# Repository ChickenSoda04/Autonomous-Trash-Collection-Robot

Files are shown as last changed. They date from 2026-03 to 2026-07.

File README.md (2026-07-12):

<div align="center" markdown="1">

# Autonomous Trash Collection

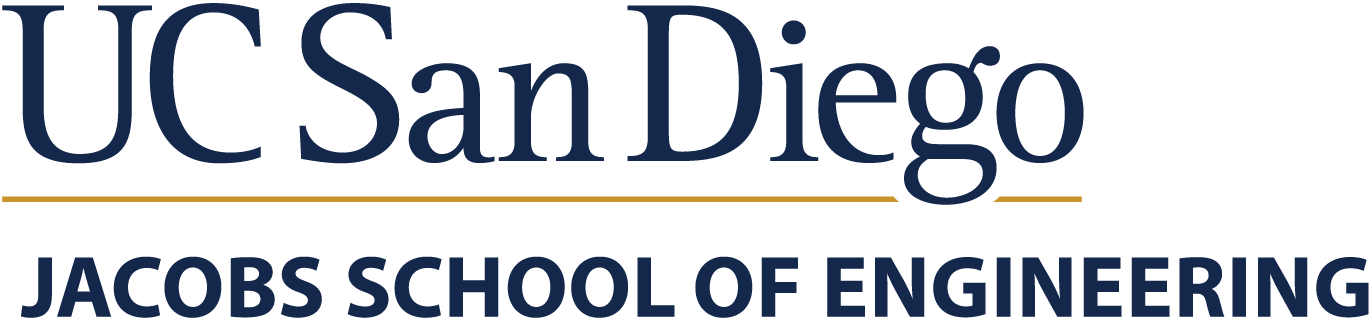
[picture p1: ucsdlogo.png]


### Team 10 & 15
### ECE/MAE 148 Final Project Winter 2026

</div>

---

## Table of Contents
1. [Team Members](#team-members)
2. [Overview](#overview)
3. [What We Promised](#what-we-promised)
4. [Accomplishments](#accomplishments)
5. [Demonstration](#demonstration)
6. [Challenges](#challenges)
7. [Project Design](#robot-arm-design)
8. [References](#references)
9. [Acknowledgments](#acknowledgments)

---

## Team Members
Team 15
- David Carrillo - MAE
- Darin Djapri 
- Lek Man- MAE
- Ryan Chen- ECE

Team 10
- Marcus Greenan - MAE
- Giovanni Clark - ECE
- Harihar Kaushik - ECE
- Lucas Johnson - ECE

---

## Overview
The **Autonomous Trash Collection** robot is a self-driving car equipped with a robotic arm that searches for and picks up litter. Using computer vision, the robot identifies trash on the ground, navigates toward it autonomously, and uses the robotic arm to collect and place it in the bin. The robot can then deliver the trash to a designated dropoff location.

---

## What We Promised

### Must Have:
- Autonomous driving and navigation
- Computer vision-based trash detection using OAK-D camera
- Robotic arm that picks up detected trash
- Deposits collected trash into an onboard bin
- Stop and approach detected trash accurately

### Nice to Have:
- Multiple trash detection and collection in a single run
- Sorting trash by type (recyclable vs. non-recyclable)
- Return to base behavior after bin is full

---

## Accomplishments
- Successfully integrated OAK-D camera with YOLOv8 model for real-time trash detection (~85% accuracy)
- Developed a ROS2 package to calculate the angle and distance from the camera to detected trash
- 3D printed a robotic arm mount for the car chassis
- Programmed the robotic arm to execute pick and place sequences upon trash detection, and integrated this functionality into a ROS2 node
- Developed a ROS2 package to facilitate centroid tracking with PID control to navigate to object
- Put together a ROS2 node based on the existing UCSD node package to identify an object, drive to it, and stop a certain distance away before triggering the arm pick-up package.
- Created a modified version of the UCSD Robocar Docker container incorporating all the aforementioned packages.

---

## Demonstration

[Full Demo Video](https://youtu.be/k4CTWPhfO1g) [Alternate Angle](https://youtu.be/v82C47zf4og)  
[Arm Demo](https://drive.google.com/file/d/1cBP66cU5hcg2m4QuWV22k2muI_fQQhjR/view)  
[Object Detection and Following Demo](https://youtu.be/KGpaVR8SIbE)  
[LiDAR Testing](https://drive.google.com/file/d/15g1UKWkqdbuN8HR0NhmWQhi5QHV1ik_H/view?usp=drivesdk)  

---

## Challenges
- **Arm calibration:** Getting the robotic arm to reliably pick up small/irregular objects required extensive tuning of servo positions and approach angles.
  - Solved by creating a multi-step approach sequence and adding a gripper feedback check.
- **Trash detection accuracy:** The model initially struggled with varying lighting conditions outdoors.
  - Improved the training dataset with augmented images under different lighting conditions, boosting accuracy.
- **Navigation precision:** Stopping at the exact distance needed for the arm to reach the trash was difficult.
  - Used LiDAR distance feedback in combination with camera angle data to fine-tune the stopping position.
- **ROS2 node conflicts:** Running the detection pipeline and arm control simultaneously caused timing conflicts.
  - Resolved by restructuring the node communication pipeline with proper topic queuing.
- **USB Bandwidth Challenges:** USB bandwidth issues stem from the fact that each group of USB 2.0 and USB 3.0 ports on the Raspberry Pi share a bus, and the high refresh rate required for each device in this application. The OAK-D initialization pipeline also switches between USB 2.0 and 3.0 pipelines, adding to port assignment confusion and bandwidth problems.
  -  These issues were partially solved using permanent device ID based assignments to ensure consistency between launches, although these were challenging to make consistent owing to permissions issues between the Docker Container and the host machine. If the permissions are made consistent, device ID based port assignments would be a good solution.
  -  Running inference on the OAK-D Lite camera saves significant bandwidth, since the device only needs to pass results over USB rather than images. Even so, the framerate had to be reduced from the standard 30 FPS to 10 FPS. The same refresh rate modification was applied to the LIDAR.
- **Power Challenges:** Power issues plagued this project. These issues were only partially solved in the interest of longevity, but safe permanent solutions are feasible. Current limiting was a recurring problem with this project, with certain actuator activations triggering brownouts.
  - Partially addressed the problem by simply using mains power to power the arm. However, this could be safely addressed by using a higher rated DC/DC converter. We were unable to source the parts needed in time, and thought it unsafe to splice more wiring to add another DC/DC converter.

---

## Robot Arm Design
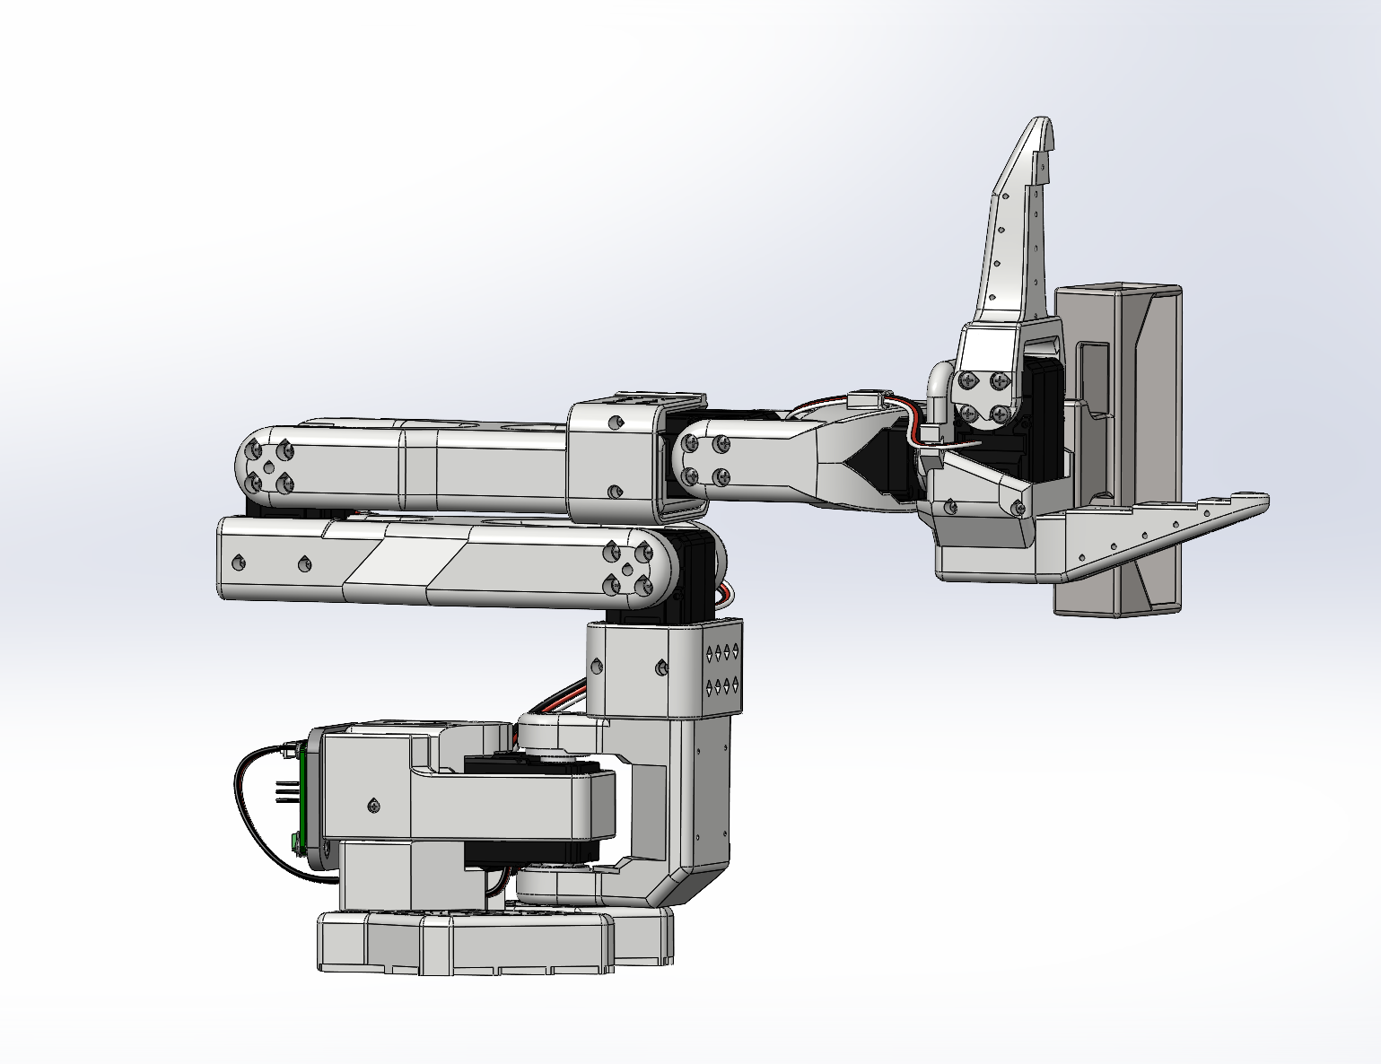
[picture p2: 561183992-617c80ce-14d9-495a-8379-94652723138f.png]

Arm Calibration Testing

## Object Navigation and Tracking

Watch the video (https://youtu.be/KGpaVR8SIbE?si=vM9rUNm2YVQ-w0Mx)

### Hardware Components List
- SO101 Arm by The Robot Studio 
- OAK-D Camera
- STS3215 Servos
- Motor Control Board
- USB-C Cable

## Car Platform

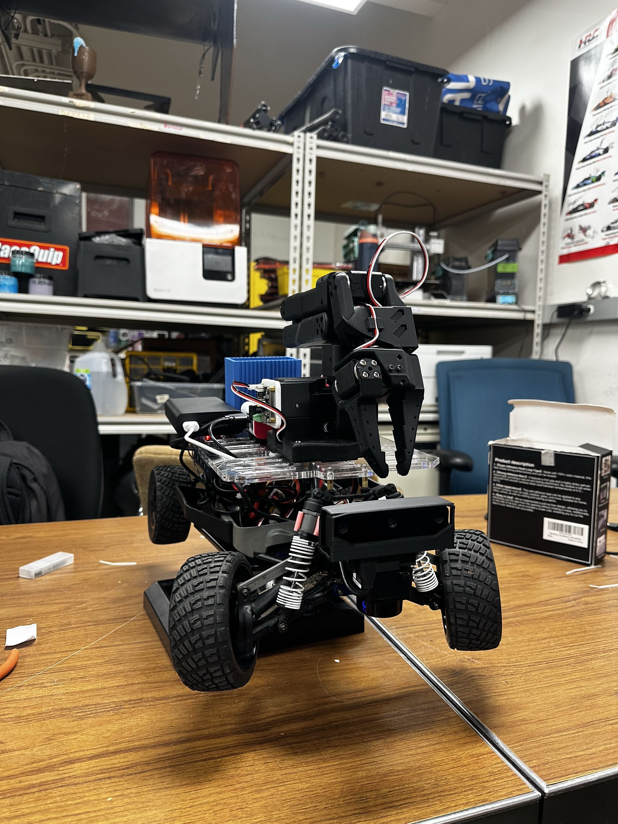
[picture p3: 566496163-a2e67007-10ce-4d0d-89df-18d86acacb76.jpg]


### Hardware Components List
- Base Driving Platform (Traxxas Chassis with Motor and Steering Servo)
- Flipsky FSESC 6.7 Pro and Antispark Switch Pro with Trampa Servo PDB
- 12V to 12V + 5V DC/DC converter (16A)
- LiPo 4S Battery
- OAK-D Lite Camera 
- LDRobot LDS19 LIDAR
- Raspberry Pi 5 8GB
- Powered USB A 3.0 Hub
- Required Cables

---

## Project Demo
Watch the video (https://youtu.be/5j4aBRYknjA)

## References
- [TheRobotStudio](https://github.com/TheRobotStudio/SO-ARM100)
- [ECE/MAE148 Documentation](https://docs.google.com/document/d/1VeWe5lWh3oB3GlEVowoPrXruzKi2Am8tP-r6KEEmcX8/edit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)
- [UCSD Robocar Framework](https://gitlab.com/ucsd_robocar2)
- [Luxonis Documentation](https://docs.luxonis.com/hardware/products/OAK-D%20Lite)
- [Trash Detection Dataset - Roboflow](https://universe.roboflow.com)
- [LDRobot LIDAR GitHub](https://github.com/ldrobotSensorTeam)
- [Luxonis Blob Converter](https://blobconverter.luxonis.com/)
- [Label Studio](https://labelstud.io/)

---

## Acknowledgments
Thank you to Professor Jack Silberman and our TAs!

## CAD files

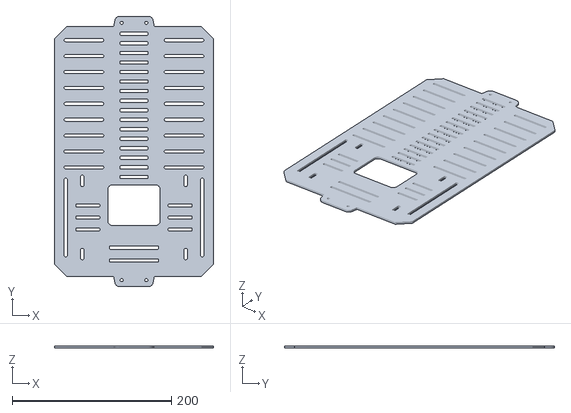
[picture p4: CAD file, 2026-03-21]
Misc_STL/DeckPlateAcl (1).stl
200.0 x 340.0 x 3.00

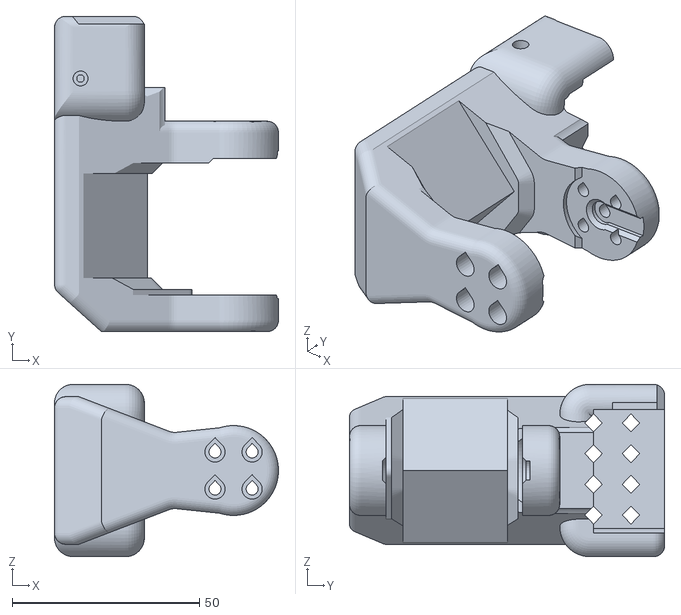
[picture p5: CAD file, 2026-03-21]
SO101_STL_Files/Rotation_Pitch_SO101.stl
59.8 x 84.2 x 46.0

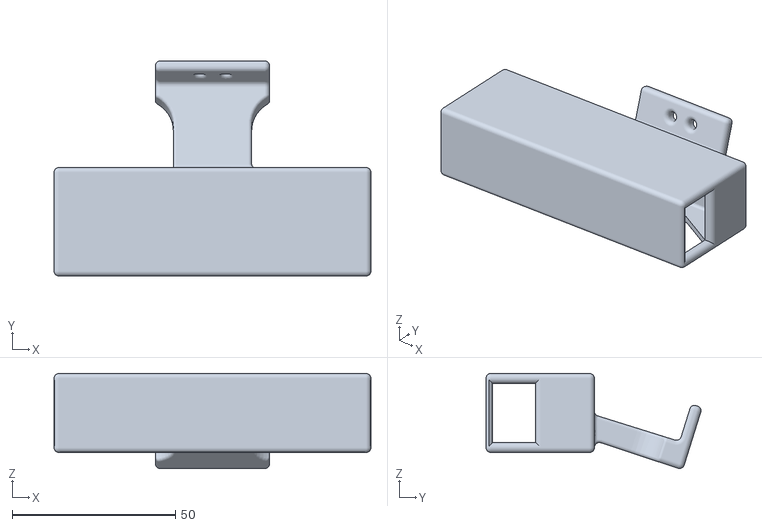
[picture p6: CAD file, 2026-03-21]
Misc_STL/RobotArmCAM (1).STL
97.0 x 65.8 x 29.1

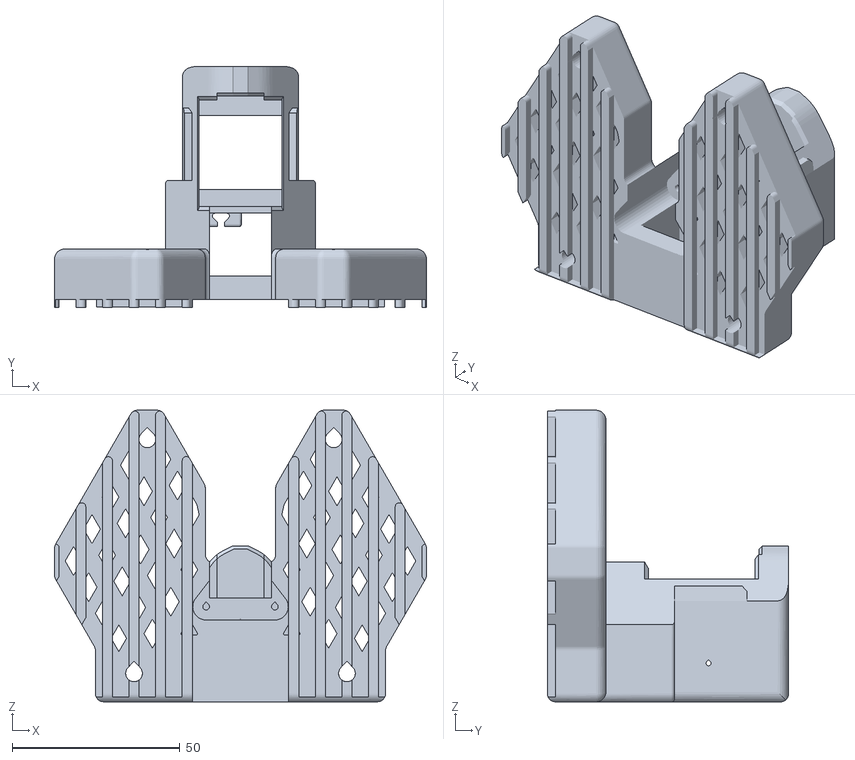
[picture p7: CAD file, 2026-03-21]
SO101_STL_Files/Base_SO101.stl
110.9 x 72.0 x 87.0

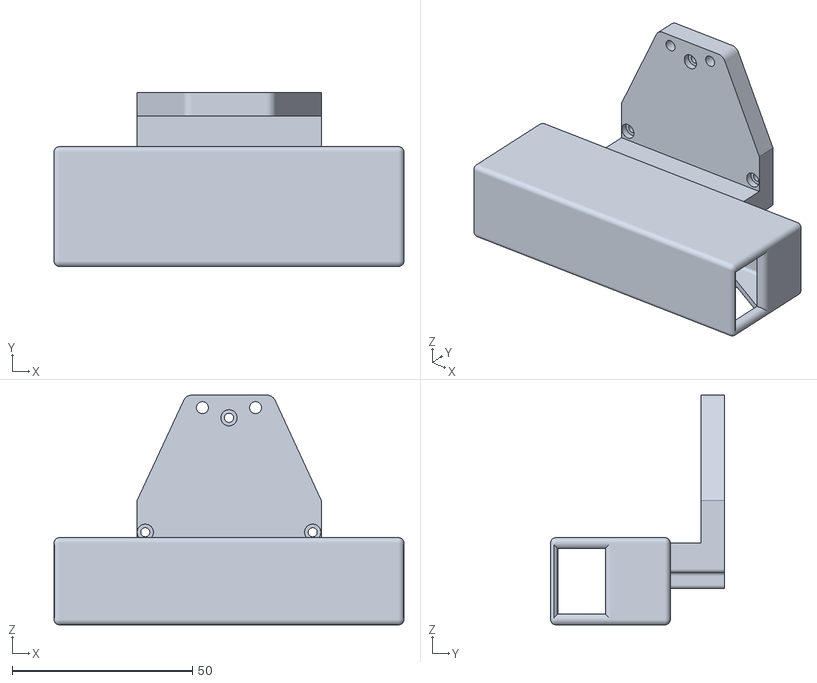
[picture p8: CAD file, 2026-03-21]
Misc_STL/Lidar+Cam (1).STL
97.0 x 48.2 x 63.7

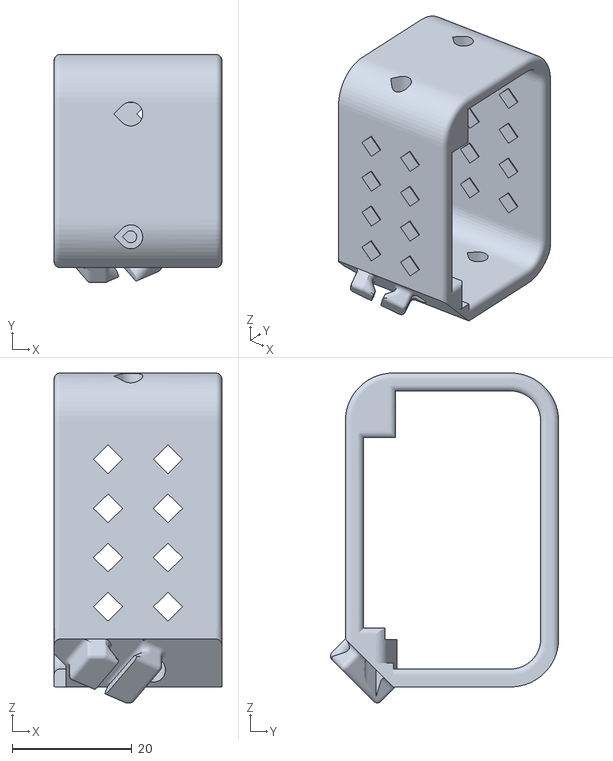
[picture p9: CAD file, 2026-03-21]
SO101_STL_Files/Motor_holder_SO101_Base.stl
28.0 x 38.1 x 55.1

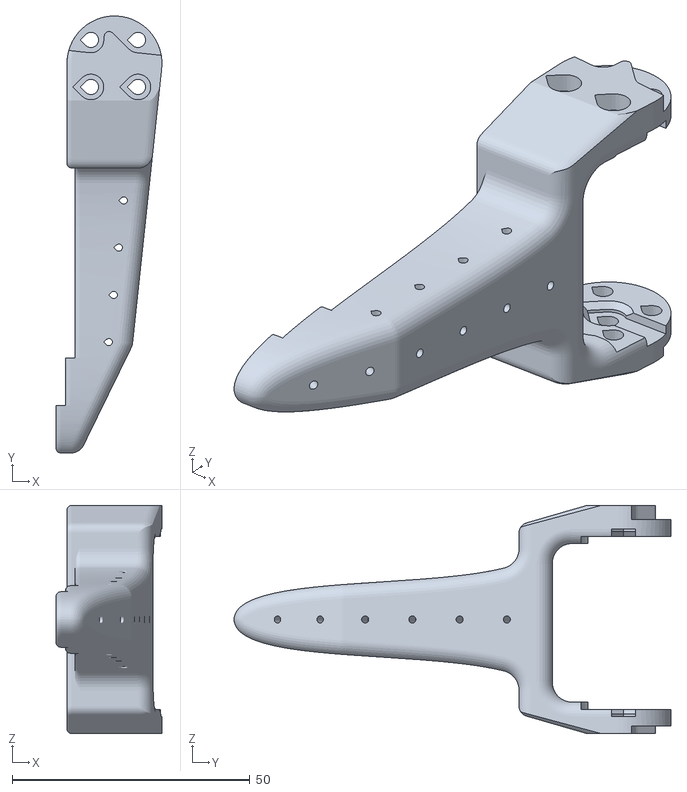
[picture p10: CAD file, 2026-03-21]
SO101_STL_Files/Moving_Jaw_SO101.stl
22.3 x 92.0 x 48.0

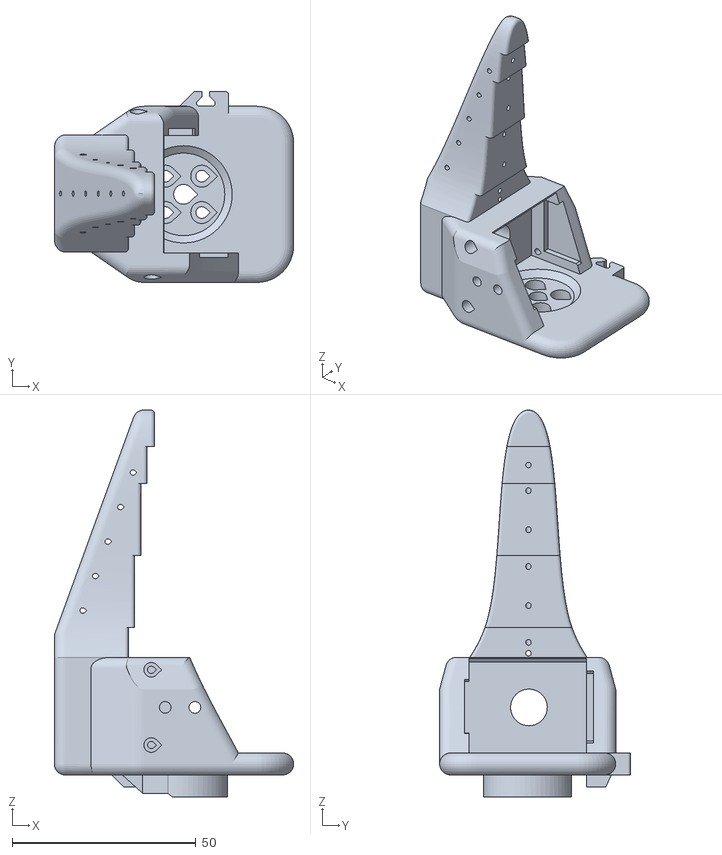
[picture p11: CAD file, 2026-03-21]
SO101_STL_Files/Wrist_Roll_Follower_SO101.stl
65.2 x 52.0 x 105.4

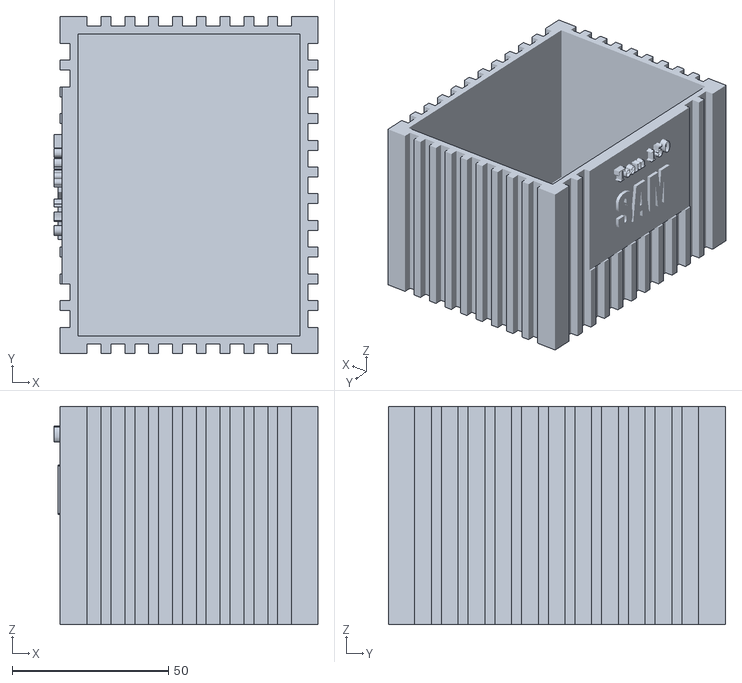
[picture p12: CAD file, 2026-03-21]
SO101_STL_Files/Trash can new 2 Mae 148 Final.stl
84.5 x 108.0 x 69.8

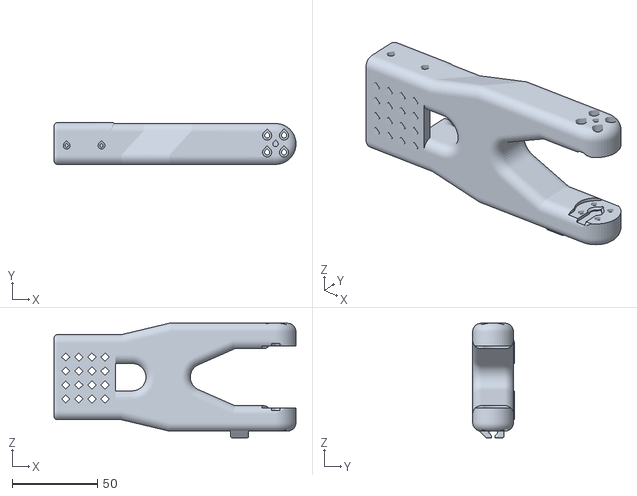
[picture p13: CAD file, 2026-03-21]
SO101_STL_Files/Upper_arm_SO101.stl
142.1 x 24.5 x 67.3

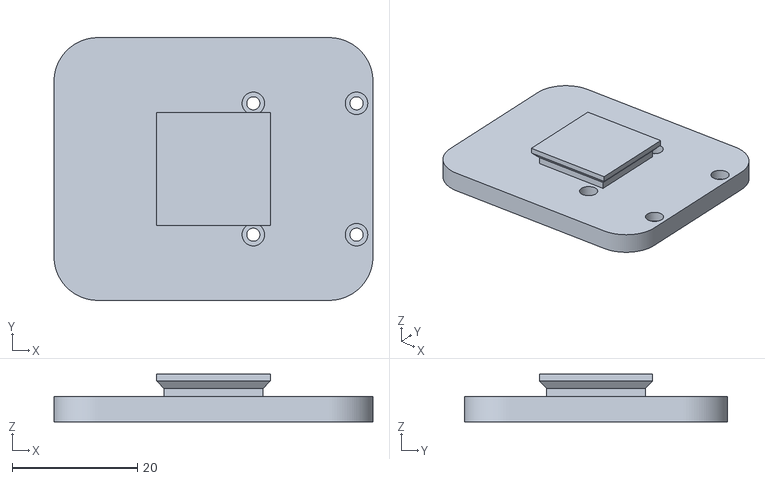
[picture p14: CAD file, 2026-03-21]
SO101_STL_Files/Seeedstudio_Mounting_Plate_SO101.stl
51.0 x 42.0 x 7.60

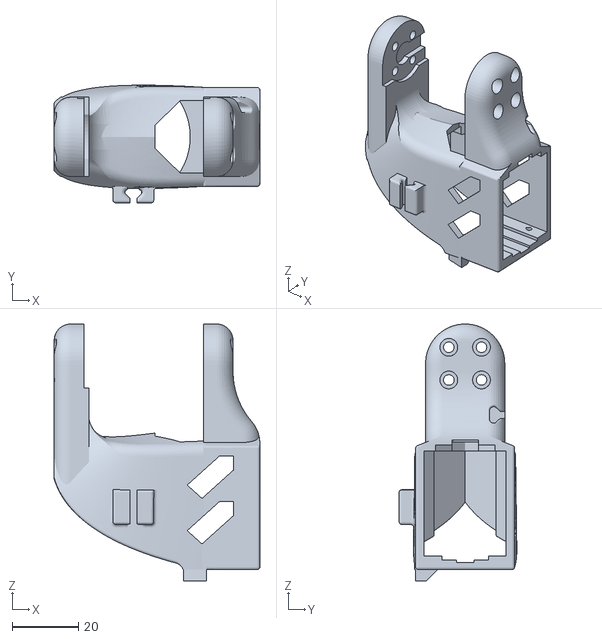
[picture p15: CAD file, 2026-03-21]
SO101_STL_Files/Wrist_Roll_Pitch_SO101.stl
62.3 x 35.7 x 77.8

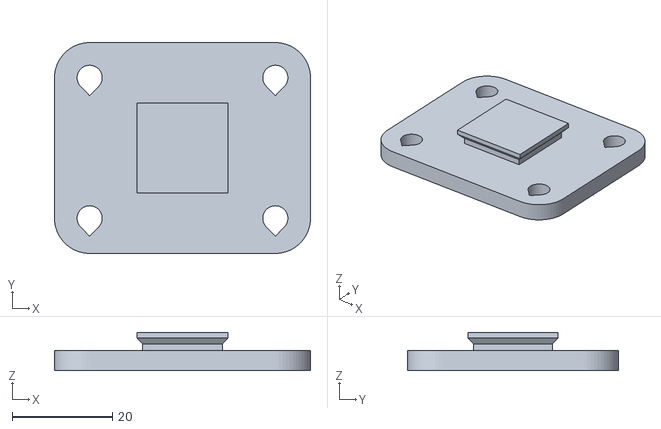
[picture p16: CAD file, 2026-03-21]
SO101_STL_Files/WaveShare_Mounting_Plate_SO101.stl
51.0 x 42.0 x 7.60

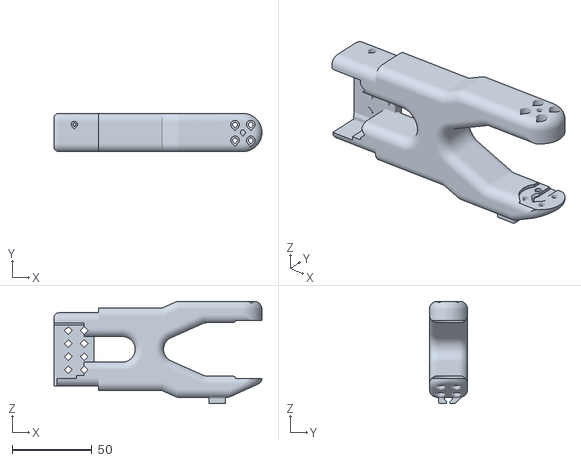
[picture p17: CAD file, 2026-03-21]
SO101_STL_Files/Under_arm_SO101.stl
130.7 x 24.0 x 64.4

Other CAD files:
SO101_STL_Files/Motor_holder_SO101_Wrist.stl
SO101_STL_Files/Base_motor_holder_SO101.stl

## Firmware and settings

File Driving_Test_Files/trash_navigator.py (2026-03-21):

#!/usr/bin/env python3
"""
trash_navigator.py
ROS2 node — OAK-D Myriad X inference + LD19 LiDAR stop.

Bandwidth optimisations:
  - Inference runs on Myriad X — only NN results cross USB, not full frames
  - No onnxruntime, no Pi CPU inference load
  - ImageManip converts video to BGR888p on-device before NN
  - maxSize=1 on all queues
  - USB2 mode — stable connection
  - Timer at 10Hz matches camera FPS
  - LiDAR reads 1 packet per loop
  - Single-threaded ROS executor
  - Preallocated numpy arrays
"""

import math
import time
import depthai
import numpy as np
import cv2
import serial
import rclpy
from rclpy.node import Node
from geometry_msgs.msg import Twist

# ── CONFIGURATION ─────────────────────────────────────────────────────────────
BLOB_PATH        = "/home/projects/best_simplified_openvino_2021.4_6shave.blob"  # Or the path to your blob
CLASSES          = ["Raisin Box"] #Make sure all these params match your model, check your data.yaml for this info
NUM_CLASSES      = len(CLASSES)
IMG_SIZE         = 416
CONF_THRES       = 0.5
IOU_THRES        = 0.4
NORM_FACTOR      = IMG_SIZE / 2.0

STOP_DISTANCE_M  = 0.16
LIDAR_PORT       = "/dev/ttyUSB0"
LIDAR_BAUD       = 230400
FORWARD_CONE     = 20.0
MIN_RANGE        = 0.15
MAX_RANGE        = 1.50
CLUSTER_DIST     = 0.08
MIN_CLUSTER_SIZE = 2
PACKETS_PER_LOOP = 1             # One LiDAR packet per loop — minimal USB traffic

KP            = 1.0
MAX_THROTTLE  = 0.2

HEADER      = 0x54
VER_LEN     = 0x2C
PACKET_SIZE = 47


# ── YOLOV8 PARSER ─────────────────────────────────────────────────────────────
def parse_yolov8(raw, conf_thres, iou_thres, img_size, nc):
    data        = np.asarray(raw, dtype=np.float32)
    total       = 4 + nc
    num_anchors = data.size // total
    data        = data.reshape(total, num_anchors).T
    normalised  = data[:, :4].max() <= 1.0

    boxes, scores, class_ids = [], [], []
    for row in data:
        cls_scores = row[4:]
        cls_id     = int(cls_scores.argmax())
        conf       = float(cls_scores[cls_id])
        if conf < conf_thres:
            continue
        cx, cy, w, h = row[:4]
        if normalised:
            cx, cy, w, h = (cx * img_size, cy * img_size,
                            w  * img_size, h  * img_size)
        x1 = max(0, int(cx - w / 2))
        y1 = max(0, int(cy - h / 2))
        x2 = min(img_size - 1, int(cx + w / 2))
        y2 = min(img_size - 1, int(cy + h / 2))
        if x2 - x1 < 2 or y2 - y1 < 2:
            continue
        boxes.append([x1, y1, x2 - x1, y2 - y1])
        scores.append(conf)
        class_ids.append(cls_id)

    if not boxes:
        return []
    idxs = cv2.dnn.NMSBoxes(boxes, scores, conf_thres, iou_thres)
    if len(idxs) == 0:
        return []
    idxs = idxs.flatten() if hasattr(idxs, 'flatten') else idxs
    return [(boxes[i], scores[i], class_ids[i]) for i in idxs]


# ── LIDAR HELPERS ─────────────────────────────────────────────────────────────
def lidar_read_packet(ser):
    try:
        b1 = ser.read(1)
        if not b1 or b1[0] != HEADER:
            return None
        b2 = ser.read(1)
        if not b2 or b2[0] != VER_LEN:
            return None
        rest = ser.read(PACKET_SIZE - 2)
        if len(rest) != PACKET_SIZE - 2:
            return None
        return b1 + b2 + rest
    except Exception:
        return None


def lidar_parse_packet(packet):
    start_angle = ((packet[5] << 8) | packet[4]) / 100.0
    end_angle   = ((packet[43] << 8) | packet[42]) / 100.0
    if end_angle < start_angle:
        end_angle += 360.0
    pts = []
    for i in range(12):
        off     = 6 + 3 * i
        dist_mm = (packet[off + 1] << 8) | packet[off]
        if dist_mm == 0:
            continue
        dist_m = dist_mm / 1000.0
        if dist_m < MIN_RANGE or dist_m > MAX_RANGE:
            continue
        angle_deg = start_angle + (end_angle - start_angle) * i / 11.0
        angle_deg = angle_deg % 360.0
        if not (angle_deg <= FORWARD_CONE or angle_deg >= (360.0 - FORWARD_CONE)):
            continue
        angle_rad = math.radians(angle_deg)
        x = dist_m * math.cos(angle_rad)
        y = dist_m * math.sin(angle_rad)
        pts.append((x, y, dist_m))
    return pts


def lidar_cluster(points):
    if not points:
        return []
    clusters = []
    current  = [points[0]]
    for i in range(1, len(points)):
        if math.hypot(points[i][0] - points[i-1][0],
                      points[i][1] - points[i-1][1]) <= CLUSTER_DIST:
            current.append(points[i])
        else:
            clusters.append(current)
            current = [points[i]]
    clusters.append(current)
    return [c for c in clusters if len(c) >= MIN_CLUSTER_SIZE]


def lidar_centroid_distance(clusters):
    best = MAX_RANGE
    for c in clusters:
        x = sum(p[0] for p in c) / len(c)
        y = sum(p[1] for p in c) / len(c)
        best = min(best, math.hypot(x, y))
    return best


# ── ROS2 NODE ─────────────────────────────────────────────────────────────────
class TrashNavigator(Node):

    def __init__(self):
        super().__init__('trash_navigator_node')
        self.publisher    = self.create_publisher(Twist, '/cmd_vel', 10)
        self.stopped      = False
        self.current_dist = MAX_RANGE

        self._init_oakd()
        self._init_lidar()

        # 10Hz matches camera FPS — no wasted loop iterations
        self.create_timer(0.1, self.navigation_loop)
        self.get_logger().info('TrashNavigator ready.')

    # ── OAK-D + Myriad X inference ────────────────────────────────────────────
    def _init_oakd(self):
        self._device = None
        self._q_nn   = None

        devices = depthai.Device.getAllAvailableDevices()
        if not devices:
            self.get_logger().error('No OAK-D device found.')
            return

        device = devices[0]
        if str(device.state) != 'XLinkDeviceState.X_LINK_UNBOOTED':
            self.get_logger().warn(
                'OAK-D not UNBOOTED: {}'.format(device.state))
            return

        pipeline = depthai.Pipeline()

        cam_rgb = pipeline.create(depthai.node.ColorCamera)
        cam_rgb.setResolution(
            depthai.ColorCameraProperties.SensorResolution.THE_1080_P)
        cam_rgb.setVideoSize(IMG_SIZE, IMG_SIZE)
        cam_rgb.setColorOrder(depthai.ColorCameraProperties.ColorOrder.BGR)
        cam_rgb.setInterleaved(False)
        cam_rgb.setFps(10)

        # Convert to BGR888p on-device before NN — no frame data crosses USB
        manip = pipeline.create(depthai.node.ImageManip)
        manip.initialConfig.setFrameType(depthai.RawImgFrame.Type.BGR888p)
        manip.setMaxOutputFrameSize(IMG_SIZE * IMG_SIZE * 3)
        cam_rgb.video.link(manip.inputImage)

        # Inference runs entirely on Myriad X
        nn = pipeline.create(depthai.node.NeuralNetwork)
        nn.setBlobPath(BLOB_PATH)
        nn.setNumInferenceThreads(2)
        nn.setNumNCEPerInferenceThread(1)
        nn.input.setBlocking(False)
        manip.out.link(nn.input)

        # Only NN results cross USB — tiny compared to full frames
        xout_nn = pipeline.create(depthai.node.XLinkOut)
        xout_nn.setStreamName("nn")
        nn.out.link(xout_nn.input)

        self._device = depthai.Device(pipeline, device, True)
        self._q_nn   = self._device.getOutputQueue(
            "nn", maxSize=1, blocking=False)
        self.get_logger().info('OAK-D Myriad X inference started.')

    # ── LiDAR init ────────────────────────────────────────────────────────────
    def _init_lidar(self):
        try:
            self._ser = serial.Serial(LIDAR_PORT, LIDAR_BAUD, timeout=0.005)
            self.get_logger().info('LiDAR opened on {}'.format(LIDAR_PORT))
        except serial.SerialException as e:
            self.get_logger().error('LiDAR error: {}'.format(e))
            self._ser = None

    # ── LiDAR distance ────────────────────────────────────────────────────────
    def _get_lidar_distance(self):
        if self._ser is None:
            return self.current_dist
        pts = []
        for _ in range(PACKETS_PER_LOOP):
            packet = lidar_read_packet(self._ser)
            if packet:
                pts.extend(lidar_parse_packet(packet))
        if not pts:
            return self.current_dist
        pts_sorted = sorted(pts, key=lambda p: math.atan2(p[1], p[0]))
        clusters   = lidar_cluster(pts_sorted)
        if not clusters:
            return self.current_dist
        return lidar_centroid_distance(clusters)

    # ── Main navigation loop ──────────────────────────────────────────────────
    def navigation_loop(self):
        twist = Twist()

        if self.stopped:
            self.publisher.publish(twist)
            return

        # LiDAR stop check
        self.current_dist = self._get_lidar_distance()
        if self.current_dist <= STOP_DISTANCE_M:
            self.stopped = True
            self.publisher.publish(twist)
            self.get_logger().warn(
                'Target reached at {:.3f}m — stopping.'.format(
                    self.current_dist))
            return

        if self._q_nn is None:
            return

        # Read NN result — only detection data, no frame pixels cross USB
        try:
            nn_msg = self._q_nn.tryGet()
        except RuntimeError as e:
            self.get_logger().warn(
                'OAK-D error — attempting reopen: {}'.format(str(e)[:60]))
            try:
                self._device.close()
            except Exception:
                pass
            self._device = None
            self._q_nn   = None
            time.sleep(5.0)
            self._init_oakd()
            return

        if nn_msg is None:
            return

        raw  = nn_msg.getFirstLayerFp16()
        dets = parse_yolov8(raw, CONF_THRES, IOU_THRES, IMG_SIZE, NUM_CLASSES)

        if not dets:
            self.get_logger().info('No detection — holding.')
            return

        best_box, best_conf, best_cls = max(dets, key=lambda d: d[1])
        bx, by, bw, bh = best_box

        obj_cx   = bx + bw / 2.0
        error_x  = (obj_cx - NORM_FACTOR) / NORM_FACTOR

        twist.linear.x  = float(MAX_THROTTLE)
        twist.angular.z = float(KP * -error_x)
        self.publisher.publish(twist)

        self.get_logger().info(
            '{} conf={:.2f}  err={:+.3f}  dist={:.3f}m'.format(
                CLASSES[best_cls], best_conf, error_x, self.current_dist))

    def destroy_node(self):
        try:
            self._device.close()
        except Exception:
            pass
        try:
            if self._ser and self._ser.is_open:
                self._ser.close()
        except Exception:
            pass
        super().destroy_node()


def main():
    rclpy.init()
    node = TrashNavigator()
    try:
        rclpy.spin(node)
    except KeyboardInterrupt:
        pass
    finally:
        node.destroy_node()
        rclpy.shutdown()


if __name__ == '__main__':
    main()

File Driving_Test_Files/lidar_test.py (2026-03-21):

import matplotlib
matplotlib.use('Qt5Agg')  # Switch to 'TkAgg' or 'QtAgg' if this fails

import math
import numpy as np
import serial
import matplotlib.pyplot as plt
import matplotlib.patches as mpatches

PORT = "COM6" # Or your COM port
BAUD = 230400
HEADER = 0x54
VER_LEN = 0x2C
PACKET_SIZE = 47
MIN_RANGE = 0.15
MAX_RANGE = 1.50
CLUSTER_DISTANCE = 0.08
MIN_CLUSTER_SIZE = 2          # Lowered from 3 — fewer points needed to form a cluster

FORWARD_CONE_DEG = 20.0

# Fewer retained points = old data drops off much faster
MAX_POINTS_ON_SCREEN = 100

# More packets drained per frame = faster visual update
PACKETS_PER_FRAME = 10

ser = serial.Serial(PORT, BAUD, timeout=0.005)  # Very short timeout
recent_points = []

def read_packet():
    while True:
        b1 = ser.read(1)
        if not b1 or b1[0] != HEADER:
            continue
        b2 = ser.read(1)
        if not b2 or b2[0] != VER_LEN:
            continue
        rest = ser.read(PACKET_SIZE - 2)
        if len(rest) != PACKET_SIZE - 2:
            continue
        return b1 + b2 + rest

def parse_packet(packet):
    start_angle = ((packet[5] << 8) | packet[4]) / 100.0
    end_angle   = ((packet[43] << 8) | packet[42]) / 100.0
    if end_angle < start_angle:
        end_angle += 360.0
    pts = []
    for i in range(12):
        off = 6 + 3 * i
        dist_mm = (packet[off + 1] << 8) | packet[off]
        if dist_mm == 0:
            continue
        dist_m = dist_mm / 1000.0
        if dist_m < MIN_RANGE or dist_m > MAX_RANGE:
            continue
        angle_deg = start_angle + (end_angle - start_angle) * i / 11.0
        angle_deg = angle_deg % 360.0
        a = angle_deg
        if not (a <= FORWARD_CONE_DEG or a >= (360.0 - FORWARD_CONE_DEG)):
            continue
        angle_rad = math.radians(angle_deg)
        x = dist_m * math.cos(angle_rad)
        y = dist_m * math.sin(angle_rad)
        pts.append((x, y, dist_m, angle_deg))
    return pts

def euclidean_distance(p1, p2):
    return math.hypot(p1[0] - p2[0], p1[1] - p2[1])

def cluster_points(points, threshold=CLUSTER_DISTANCE):
    if not points:
        return []
    clusters = []
    current_cluster = [points[0]]
    for i in range(1, len(points)):
        if euclidean_distance(points[i - 1], points[i]) <= threshold:
            current_cluster.append(points[i])
        else:
            clusters.append(current_cluster)
            current_cluster = [points[i]]
    clusters.append(current_cluster)
    return clusters

def compute_centroid(cluster):
    x_avg = sum(p[0] for p in cluster) / len(cluster)
    y_avg = sum(p[1] for p in cluster) / len(cluster)
    d_avg = math.hypot(x_avg, y_avg)
    return (x_avg, y_avg, d_avg)

EMPTY = np.empty((0, 2))

# ── Radar figure ──────────────────────────────────────────────────────────────
plt.ion()
fig = plt.figure(figsize=(8, 8), facecolor='#0a0a0a')
ax  = fig.add_subplot(111, facecolor='#0a0a0a')
ax.set_aspect('equal')
ax.set_xlim(-MAX_RANGE - 0.1, MAX_RANGE + 0.1)
ax.set_ylim(-MAX_RANGE - 0.1, MAX_RANGE + 0.1)
ax.axis('off')

for r in [0.25, 0.50, 0.75, 1.00, 1.25, 1.50]:
    ax.add_patch(plt.Circle((0, 0), r, color='#1a3a1a', fill=False, linewidth=0.8))
    ax.text(0, r + 0.02, f'{r:.2f}m', color='#2a6a2a', fontsize=7, ha='center', va='bottom')

for deg in range(0, 360, 30):
    rad = math.radians(deg)
    ax.plot([0, MAX_RANGE * math.cos(rad)], [0, MAX_RANGE * math.sin(rad)],
            color='#1a3a1a', linewidth=0.6)
    lx = (MAX_RANGE + 0.08) * math.cos(rad)
    ly = (MAX_RANGE + 0.08) * math.sin(rad)
    ax.text(lx, ly, f'{deg}°', color='#2a6a2a', fontsize=7, ha='center', va='center')

ax.add_patch(mpatches.Wedge((0, 0), MAX_RANGE + 0.1,
                             -FORWARD_CONE_DEG, FORWARD_CONE_DEG,
                             color='#002800', alpha=0.6))

for sign in [-1, 1]:
    rad = math.radians(sign * FORWARD_CONE_DEG)
    ax.plot([0, (MAX_RANGE + 0.1) * math.cos(rad)],
            [0, (MAX_RANGE + 0.1) * math.sin(rad)],
            color='#00aa00', linewidth=1.0, linestyle='--')

ax.plot(0, 0, 'o', color='#00ff41', markersize=5)
ax.annotate('', xy=(0.18, 0), xytext=(0, 0),
            arrowprops=dict(arrowstyle='->', color='#00ff41', lw=1.5))

scatter_fwd  = ax.scatter([], [], s=8,   color='#00ff41', alpha=0.85, zorder=3)
scatter_cent = ax.scatter([], [], s=120, color='#ff4444', marker='+',
                          linewidths=2.5, zorder=5)

ax.text(-MAX_RANGE - 0.08, MAX_RANGE + 0.05,
        'LD19 Live Scan', color='#00ff41', fontsize=11, fontweight='bold', va='top')
dist_text  = ax.text(-MAX_RANGE - 0.08, MAX_RANGE - 0.05,
                     'Forward: --', color='#ff4444',
                     fontsize=14, fontweight='bold', va='top')
stats_text = ax.text(MAX_RANGE - 0.05, MAX_RANGE + 0.05,
                     '', color='#00ff41', fontsize=8, va='top', ha='right')
ax.text(0, -(MAX_RANGE + 0.08), f'Cone: ±{FORWARD_CONE_DEG}°',
        color='#2a6a2a', fontsize=8, ha='center', va='top')

plt.tight_layout(pad=0.3)
plt.pause(0.1)

print(f"Window open — cone: ±{FORWARD_CONE_DEG}°\n")

frame_count = 0

try:
    while True:
        pts_this_frame = []
        for _ in range(PACKETS_PER_FRAME):
            try:
                packet = read_packet()
                pts_this_frame.extend(parse_packet(packet))
            except Exception:
                break

        if not pts_this_frame:
            plt.pause(0.001)
            continue

        frame_count += 1

        # Replace buffer entirely each frame rather than appending and trimming —
        # this means only the freshest points are ever shown
        recent_points.clear()
        recent_points.extend(pts_this_frame[-MAX_POINTS_ON_SCREEN:])

        forward_centroid = None

        if recent_points:
            fwd_xy   = [(p[0], p[1]) for p in recent_points]
            asorted  = sorted(recent_points, key=lambda p: math.atan2(p[1], p[0]))
            axy      = [(p[0], p[1]) for p in asorted]
            clusters = [c for c in cluster_points(axy) if len(c) >= MIN_CLUSTER_SIZE]

            if clusters:
                centroids        = [compute_centroid(c) for c in clusters]
                forward_centroid = min(centroids, key=lambda c: c[2])
                dist_m           = forward_centroid[2]
                print(f"Object centroid: {dist_m:.3f} m  "
                      f"(x={forward_centroid[0]:.3f}, y={forward_centroid[1]:.3f})")
                dist_text.set_text(f'Forward: {dist_m:.3f} m')
            else:
                dist_text.set_text('Forward: no object')

            scatter_fwd.set_offsets(np.array(fwd_xy))
        else:
            scatter_fwd.set_offsets(EMPTY)
            dist_text.set_text('Forward: no object')

        scatter_cent.set_offsets(
            np.array([[forward_centroid[0], forward_centroid[1]]])
            if forward_centroid is not None else EMPTY
        )

        stats_text.set_text(f'Points: {len(recent_points)}\nFrames: {frame_count}')

        plt.pause(0.001)
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
